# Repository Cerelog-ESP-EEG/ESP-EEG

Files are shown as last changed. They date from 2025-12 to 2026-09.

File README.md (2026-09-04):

# **Cerelog ESP-EEG** 

<table>
  <tr>
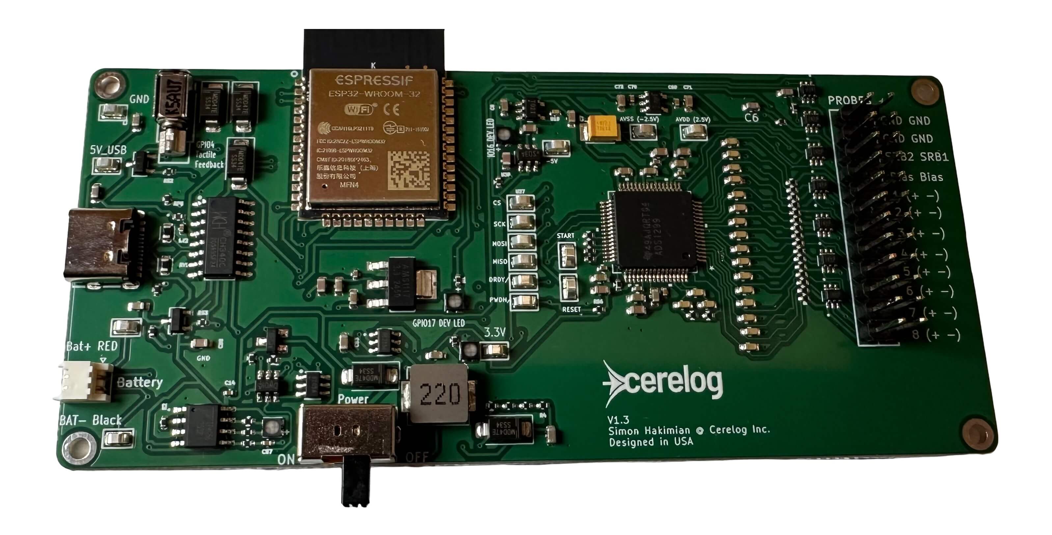
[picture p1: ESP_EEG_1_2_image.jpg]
Cerelog Board V1
    <td align="center"></td>
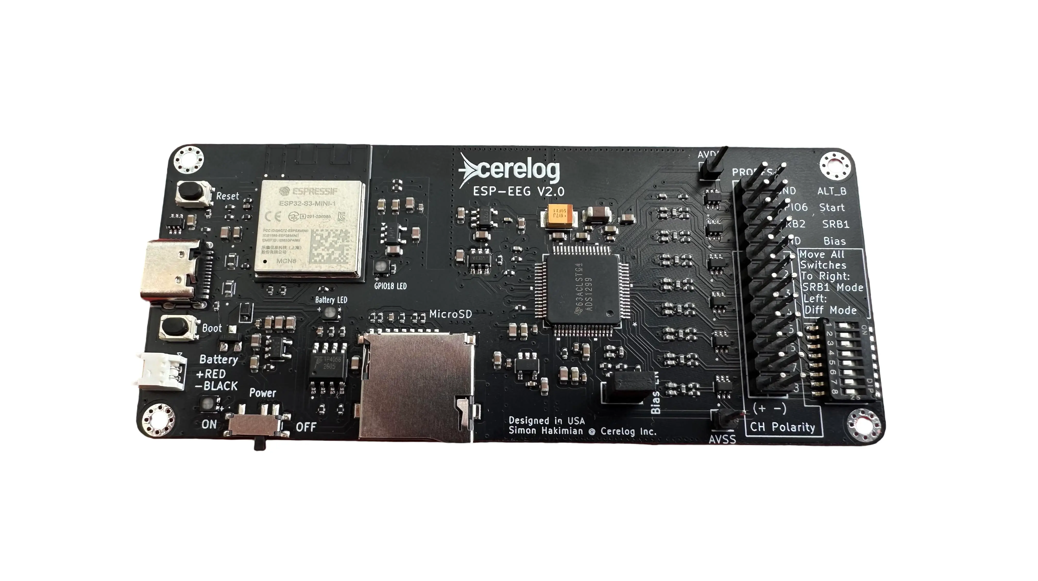
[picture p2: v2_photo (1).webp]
Cerelog Board V2
    <td align="center"></td>
  </tr>
  <tr>
    <td align="center"><b>V1</b></td>
    <td align="center"><b>V2</b></td>
  </tr>
  <tr>
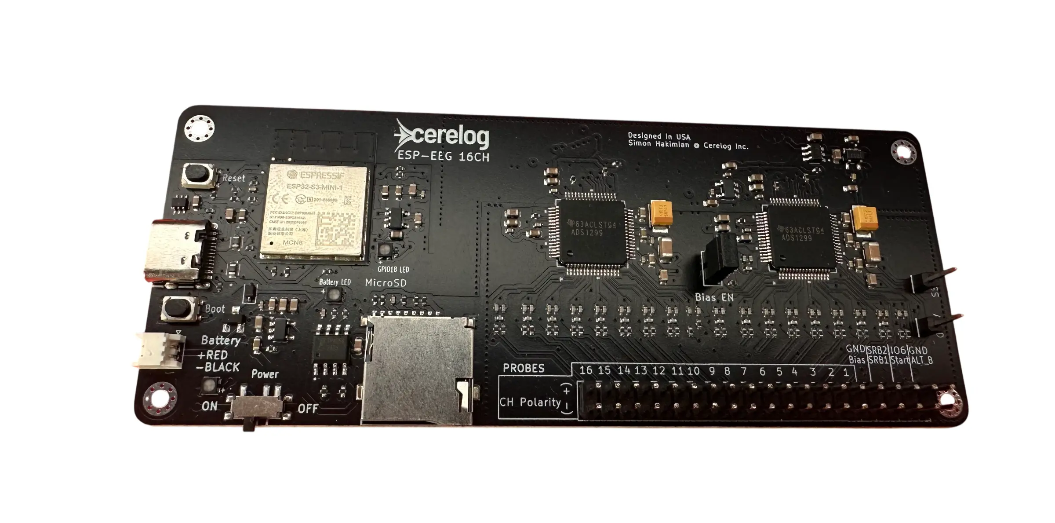
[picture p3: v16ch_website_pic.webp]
16ch ESP-EEG
    <td align="center" colspan="2"></td>
  </tr>
  <tr>
    <td align="center" colspan="2"><b>16CH ESP-EEG</b></td>
  </tr>
</table>

##  High-precision 8-channel biosensing board designed for EEG, EMG, ECG, and Brain Computer Interface (BCI) research applications

www.cerelog.com   and   **Product Page (Assembled Units Available)**: [Here](https://www.cerelog.com/eeg_researchers.html) 

Need Help or have a question? [Discord Chat Community](https://discord.com/invite/fVYf44JTua)

Open Source Firmware, Software & Schematic included on this page

# Helpful Links

Contact: simon@cerelog.com

Need Help or have a question? [Discord Chat Community](https://discord.com/invite/fVYf44JTua)

Product Page: [Here](https://www.cerelog.com/eeg_researchers.html)

Product Usage Guide : [Here](https://www.cerelog.com/eeg_researchers_guide.html) and **See Instructions file above for device usage**

Video Product Overview: [Here](youtube.com/watch?v=6XKdIbguI00&embeds_referring_euri=https%3A%2F%2Fwww.cerelog.com%2F)

3D Print your own case [Here](https://github.com/Cerelog-ESP-EEG/3D-print-Case/tree/main)

Connecting Photo

Helpful [troubleshooting guide](https://github.com/Cerelog-ESP-EEG/Troubleshooting_connection/tree/main )

# Why Cerelog's ESP-EEG? 

## Easy to use Software compatability:

## Compatable with **OpenBCI Gui (Custom fork)** via **Lab Streaming Layer (LSL) ** protocol [(What is LSL?)](https://labstreaminglayer.org/#/) 

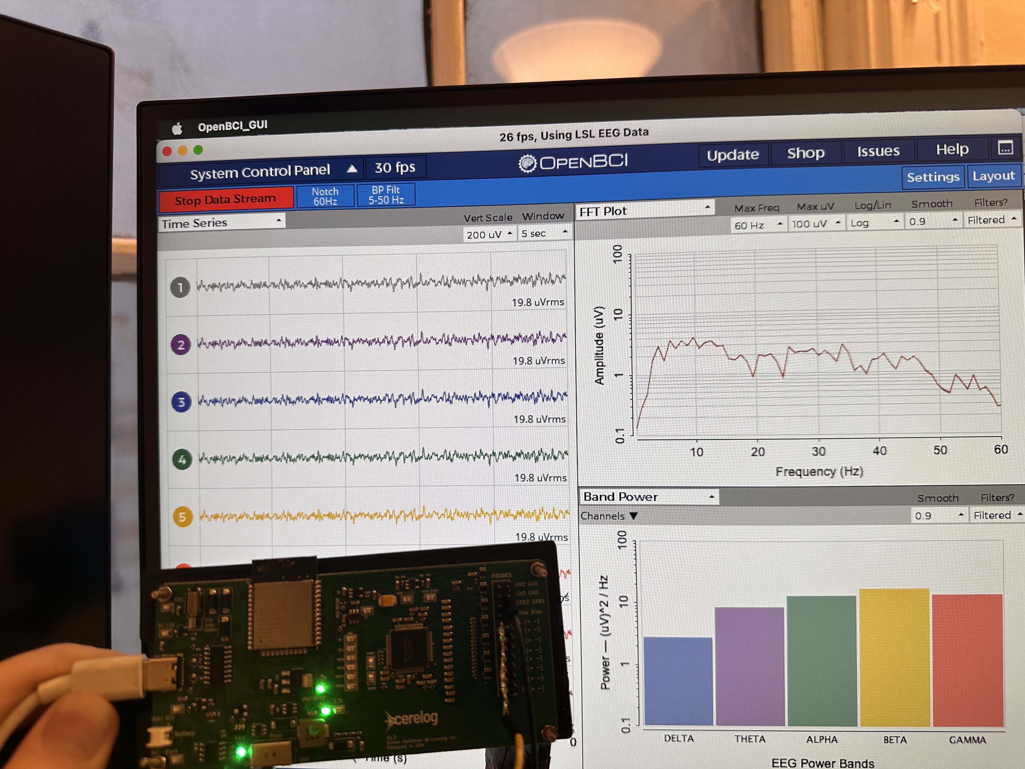
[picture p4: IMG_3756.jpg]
Demo


## USING the custom Forked OpenBCI GUI: 
Setup instructions and LSL Custom Python connection script :  [Here](https://github.com/Cerelog-ESP-EEG/How-to-use-OpenBCI-GUI-fork)

A modified OpenBCI Gui has been forked above so you can visualize data easily and stream to other platforms. This works with it's LSL streaming capability via a special python script (in link above)!

ESP-EEG’s Python client software can stream data via the standard neuroscience software communication protocol Lab Streaming Layer. This means you can stream  directly to your favorite neuroscience software or Matlab running on your laptop or remote computers, record data streams, and integrate ESP-EEG's data with other data streams.

## Stream data to Brainflow API for complex data analysis :


Instructions on how to collect data from device with Brainflow API custom instance: [Here](https://www.cerelog.com/eeg_researchers_guide.html)

and

Custom instance of Brainflow Repo: [Here](https://github.com/shakimiansky/Shared_brainflow-cerelog) for collecting data with the device. 

Note: Test script to quickly view plot and aquire data -> Run 'Shared_brainflow-cerelog/python_package/cerelog_tests/filtered_plot.py' from in above repo. (Must download and run with full Brainflow instance to use)

**2 Quick Videos Using Cerelog ESP-EEG with Brainflow:**

Make sure to read the above linked guide as it is very detailed. If you get stuck with setup, checkout these videos below:

[ESP-EEG with Brainflow](https://www.youtube.com/watch?v=hLSeSTvoRPI)  

[General Product usage Overview Video](youtube.com/watch?v=6XKdIbguI00&embeds_referring_euri=https%3A%2F%2Fwww.cerelog.com%2F)

**Link above links to youtube videos**

## Demo of EMG
# ESP-EEG Robotic Hand Controller 🤖

A demonstration of using the EMG capability of the ESP-EEG bio-signal sensor to control a robotic hand.

ESP-EEG Robotic Hand Demo (https://youtube.com/shorts/xjNg0UMrPlc?si=EgGIO7fhjGFAiRqD)  
*(Click the image above to watch the demo on YouTube)*

[Github code for EMG robotic hand control](https://github.com/Cerelog-ESP-EEG/Robotic_Hand_EMG_-ESP-EEG_Cerelog-)

## Demo of
# Playing Pong with DIY Brain Computer Interface w/ (Cerelog ESP-EEG) using SSVEP Tech 🤖

A demonstration of using the ESP-EEG bio-signal sensor to play Pong using SSVEP technology.

Playing Pong with DIY Brain Computer Interface Demo (https://www.youtube.com/watch?v=3dJWuXLpif8)
*(Click the image above to watch the demo on YouTube)*

[Instructables: Playing Pong With Your Mind – DIY Brain Computer Interface](https://www.instructables.com/Playing-Pong-With-Your-Mind-DIY-Brain-Computer-Int/)

 ## PhantomLoop Integration — Browser Based Neural Decoder *(Beta Testing)*         
                                                                                     
  **A decoder is a small program — usually a machine-learning model — that looks at  
  those signals and guesses what the person was thinking or trying to do.**          
                                                                                     
  A community-built browser-based decoder playground. Stream live EEG data from your 
  ESP-EEG, run an ML model on it, and see predicted vs. actual outputs side by side —
   no local install needed. Built by community member yelabbassi; third-party.       
                                                                                     
  [Learn more about PhantomLoop
  →](https://www.cerelog.com/community_phantomloop.html)

## NEW: WiFi Support - (Beta Testing) - For Use With OpenBCI GUI Fork / LSL
WiFi Logo

[More info](https://github.com/Cerelog-ESP-EEG/WiFi_Support)

## 📉 Superior Noise Reduction (Closed-Loop Bias)
Unlike many consumer EEG devices that use "open-loop" or passive grounding strategies, the ESP EEG implements a **True Closed-Loop Active Bias** (Drive Right Leg).

*   **The Problem:** Many competitors leave the bias feedback loop open, rendering the noise cancellation ineffective against movement artifacts and 50/60Hz hum. Their bias pin effectively becomes the average of the supply rails and acts as a ground on their device making the bias pin not function as effectively intended on the ADS1299 datasheet.
*   **Our Solution:** We utilize the full capability of the ADS1299 to measure the common-mode signal, invert it, and actively drive it back into the body.
*   **The Result:** A significantly lower noise floor and fewer artifacts, allowing for research-grade data capture even in non-shielded environments.

# Hardware Overview

View hardware folder for device schematic

## 🔌 Hardware Pinout & Indicators
*   **Status LED (GPIO 17):**
    *   🟢 **Solid On:** Firmware loaded, ready to stream.
    *   ⚫ **Off:** Board not powered or boot failure.
*   **Battery LED:**
    *   🔴 **Red:** Charging.
    *   🟢 **Green:** Fully Charged.
*   **Battery Connector:** JST-PH 1.25mm (Red = +, Black = -). *Supports 3.7V LiPo.*
*   **Electrodes:** Standard touch-proof headers. (Pins 1-8 = Signal, SRB1 = Reference).
## ⚡ Technical Specifications
| Feature | Specification |
| :--- | :--- |
| **ADC** | Texas Instruments ADS1299 (24-bit, Research Grade) |
| **Channels** | 8 Differential Channels + 1 Active Bias (Noise Cancellation) |
| **Sample Rate** | 250 SPS (Default)  |
| **Processor** | ESP32-WROOM-DA (Dual Core, WiFi/BT capable) |
| **Connectivity** | USB-C (Data/Power) & WiFi/Bluetooth (Hardware Ready) |
| **Montage** | Referential (SRB1 = Ref) by default. Configurable to Sequential. See firmware folder for more information|

# Firmware

View firmware folder for firmware and modification instructions

# ⚠️ CRITICAL SAFETY WARNING
**NON-ISOLATED DEVICE: BATTERY OPERATION REQUIRED**

This device **does not** contain galvanic isolation circuitry. To ensure user safety and prevent ground loops:
1.  **ALWAYS** use this device with a laptop running on **BATTERY POWER**.
2.  **NEVER** connect this device to a computer that is plugged into a wall outlet (Mains Power).
3.  **NEVER** use this device on a desktop computer.

Failure to follow these instructions introduces a risk of electric shock in the event of a mains surge and will significantly degrade signal quality due to ground noise.

# Important Notice
This product is intended for research, engineering, and educational purposes only. It is not a medical device and has not been evaluated by the FDA. The product is not UL or FCC certified.

This evaluation board/kit is intended for use for ENGINEERING DEVELOPMENT, DEMONSTRATION, OR EVALUATION PURPOSES ONLY and is not considered by Cerelog Inc. to be a finished end-product fit for general consumer use.

We expressly disclaim any liability whatsoever for any direct, indirect, consequential, incidental or special damages, including, without limitation, lost revenues, lost profits, losses resulting from business interruption or loss of data, arising from the use of this product.

Only plug this device into a computer running off of battery power such as a Laptop running on its own battery supply or a raspberry pi powered by a portable battery bank. Do not connect to a mains powered device such as a PC because it is not isolated in the event of a power surge. 

Cerelog Inc. assumes no liability for the performance, suitability, or use of any third-party products linked or recommended on this website.

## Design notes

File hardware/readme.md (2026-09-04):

# ESP EEG Hardware Reference

This directory contains the schematics for the ESP EEG platform by Cerelog Inc.

We love the hacker community! We explicitly grant permission for **Personal & Educational Use**.

*   **Can I build my own ESP EEG?**
     If you are a student, hobbyist, or researcher, you are welcome to use our schematics to layout and assemble your own version of this board for your own personal use.

*   **Can I sell the board I built?**
    NO. You may not sell devices based on this design. The license is strictly **Non-Commercial**.

*   **Where are the PCB Layout files?**
    We do not release the PCB layout (Gerber) files. To build your own, you will need to re-route the PCB yourself using the provided schematic. We encourage this as an advanced learning exercise in mixed-signal design!

## ⚠️ Licensing & Cloning Policy
**The hardware design files in this repository are strictly for NON-COMMERCIAL use.**

*   ✅ **Students/Researchers:** You are free to view these schematics to understand your data, debug your board, or modify your own unit.
*   ✅ **Hobbyists:** You are free to repair your own board.
*   ❌ **Commercial Entities:** You may **NOT** use these files to manufacture boards for sale.

**Why?**
Cerelog Inc. is a small, independent company. The sales of this hardware support the development of the open-source firmware, software, and future products. 
We have chosen **not** to release the PCB layout (Gerber) files at this time to prevent low-quality clones from flooding the market and undermining our ability to support this platform.

## 📂 Contents
*   v1,v2, 16CH ESP-EEG Full circuit diagrams for educational and repair purposes.

## ⚡ Safety Disclaimer
**THIS IS NOT A MEDICAL DEVICE.**
This hardware is for research and development purposes only. It is not intended for the diagnosis or treatment of any disease. Always use battery power when connected to a human subject.

## 📜 License
The documentation in this folder is released under the **Creative Commons Attribution-NonCommercial-ShareAlike 4.0 (CC-BY-NC-SA 4.0)** license.

> **Summary:** You can remix, adapt, and build upon this work non-commercially, as long as you credit Cerelog Inc. and license your new creations under the identical terms.

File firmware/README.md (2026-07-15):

## How to flash Firmware with Arduino IDE (Read Carefully!)

Modifying the firmware is necessary to:

- **Change Electrode Montage:** Switch from the default Referential mode to Sequential mode. Sequential mode measures the difference between P and N pins directly, requiring two adapters.
- **Adjust Gain:** Change the Programmable Gain Amplifier (PGA) setting (1, 2, 4, 6, 8, 12, or 24).
- **Control Peripherals:** Write custom code to activate the haptic feedback motor or use the debug LEDs.
- **Change Sample Rate:** This is a highly advanced modification. Altering the sample rate or resolution will change the data stream format and will require you to rewrite the data parsing logic in your software.

I reccomend reading the TIADS1299 datasheet to understand what register changes are needed for what firmware mods. If you have an issue email support@cerelog.com

### Configuring the Arduino IDE

Before flashing `esp32_firmware.ino`, you must configure the IDE with the correct settings:

### Special Arduino IDE Flashing Instructions

> [!CAUTION]
> Caution!!!! You must read the below or the flash wont work

**Board:** Navigate to **Tools > Board > ESP32 Arduino** and select `ESP32 WROOM DA Module`.

> [!IMPORTANT]
> It must be **ESP32 WROOM DA Module** — not the generic "ESP32 Dev Module". Picking the wrong one will flash but the board won't enumerate correctly.

**Port:** Navigate to **Tools > Port** and select the COM port corresponding to your Cerelog board.

> [!WARNING]
> Any other ESP32 name and it will likely not flash! Also, check that the serial rate setting in the Arduino IDE isnt set to the max setting, sometimes its too fast of an upload speed

> [!CAUTION]
> Caution!!!! If not flashing, check that the baud rate setting isn't too high. An upload speed of 115200 is ok but 921600 is too high and too fast of an upload speed. Navigate to **Tools > Upload speed** to check

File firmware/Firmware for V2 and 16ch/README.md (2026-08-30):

# $\textcolor{green}{\textbf{\textsf{Additional Flashing Instructions for V2 and 16 Channel PCBs}}}$

To flash firmware on the **V2** and **16 channel** boards you *must* use the **Arduino IDE**.
The sketch to flash is [`V2_FW/V2_FW.ino`](V2_FW/V2_FW.ino).

---

## $\textcolor{red}{\textbf{\textsf{!! CRITICAL SETTINGS - READ CAREFULLY !!}}}$

**These settings are NOT default and are REQUIRED.**
$\textcolor{red}{\textsf{Without them, the flash may succeed but}}$ $\textcolor{red}{\textsf{the firmware WILL NOT WORK and you}}$ $\textcolor{red}{\textsf{WILL NOT be able to log data.}}$

Set all three in the Arduino IDE **before** you hit Upload:

| # | Setting | Where | Value |
|:-:|---|---|---|
| **1** | Board | `Tools -> Board` | `ESP32-S3 Dev Module` |
| **2** | CDC on Boot | `Tools -> CDC on Boot` | `Enabled` |
| **3** | USB Mode | `Tools -> USB Mode` | `Hardware CDC and JTAG` |

> [!CAUTION]
> **DO NOT SKIP STEPS 2 AND 3.** The flash will appear to succeed, but the firmware will not function and data logging will not work.

---

## If the Flash Fails

| Symptom | Fix |
|---|---|
| Upload errors out / does not complete | `Tools -> Flash Size` &rarr; set to `4MB (32Mb)` |

---

$\textcolor{gray}{\rule{1000px}{8px}}$

# Special Extra Features in Hardware that Users May Desire to Modify Firmware to Accommodate

## Enhanced Hardware Access

The signals below are **broken out on the board but are not used by the stock firmware**. They are here for
users who want to extend the firmware for their own applications.

### $\textcolor{dodgerblue}{\textbf{\textsf{Battery monitoring}}}$ exposed on-board via ESP32 GPIO for custom firmware

Battery life can be monitored by the user: **IO0 (ADC1_CH0)** senses the battery through a resistor divider
network — multiply the measured voltage by **2** to get the real battery voltage.

### $\textcolor{dodgerblue}{\textbf{\textsf{Event sync trigger}}}$ exposed on-board via ESP32 GPIO for custom firmware

Event sync trigger input: **IO6 (ADC1_CH5)** is broken out from the ESP32 for an external trigger —
**3.3&nbsp;V max**, with a current-limiting input resistor. Modify the existing firmware to accept the trigger
for tests that need a sync.

### Quick reference

| Signal | GPIO | ADC channel | Notes |
|---|---|---|---|
| Battery sense | `IO0` | `ADC1_CH0` | Resistor divider — multiply reading by **2** |
| Event sync trigger | `IO6` | `ADC1_CH5` | **3.3 V max**, current-limiting input resistor |

> [!NOTE]
> Hardware capability only — not coded into the default firmware. Intended for users modifying the firmware
> for custom applications.

> [!WARNING]
> Just like the OpenBCI Cyton, the trigger input is **not opto-isolated** — the user is responsible for the
> safety of whatever they plug into it.

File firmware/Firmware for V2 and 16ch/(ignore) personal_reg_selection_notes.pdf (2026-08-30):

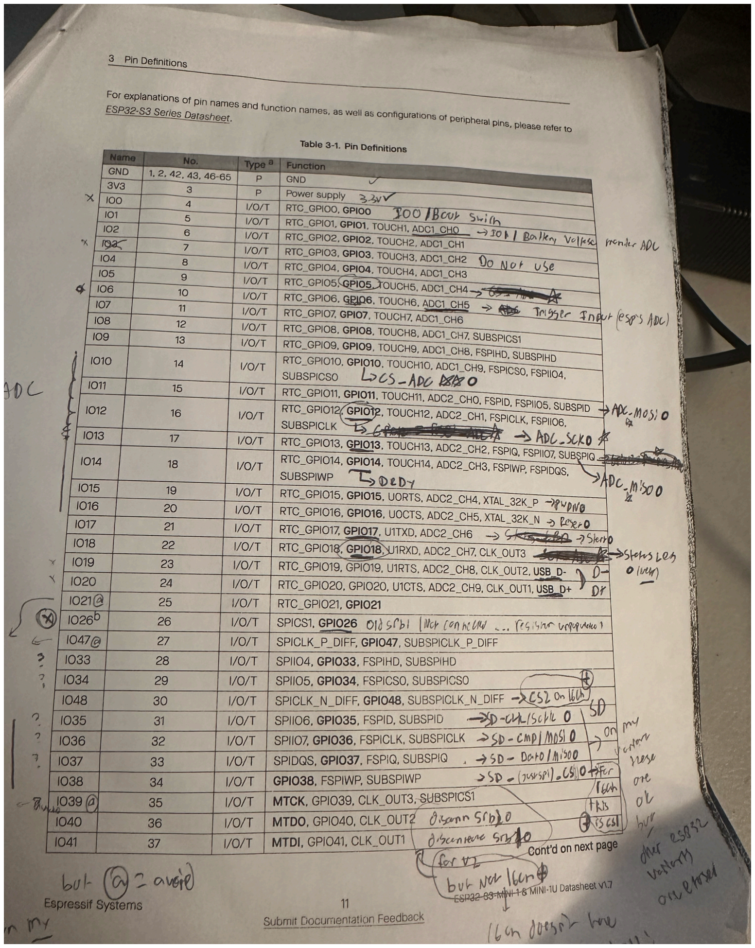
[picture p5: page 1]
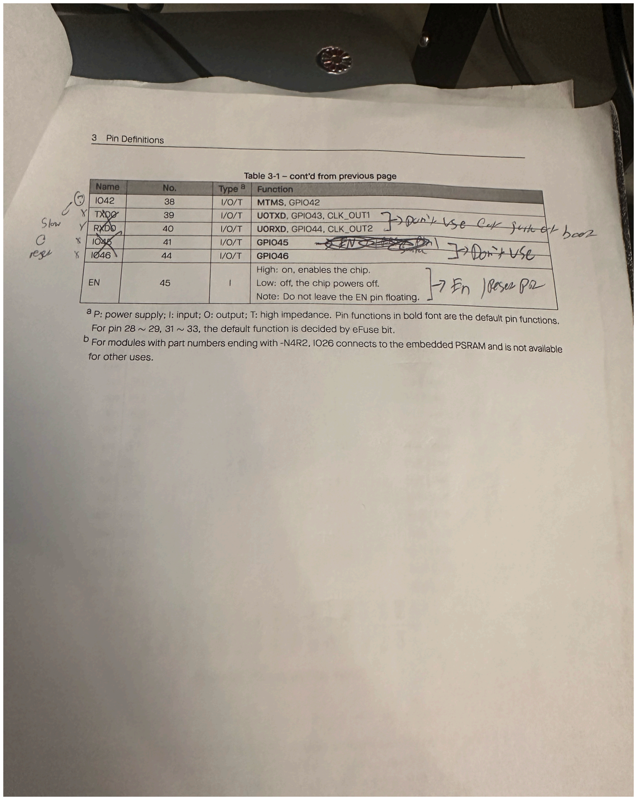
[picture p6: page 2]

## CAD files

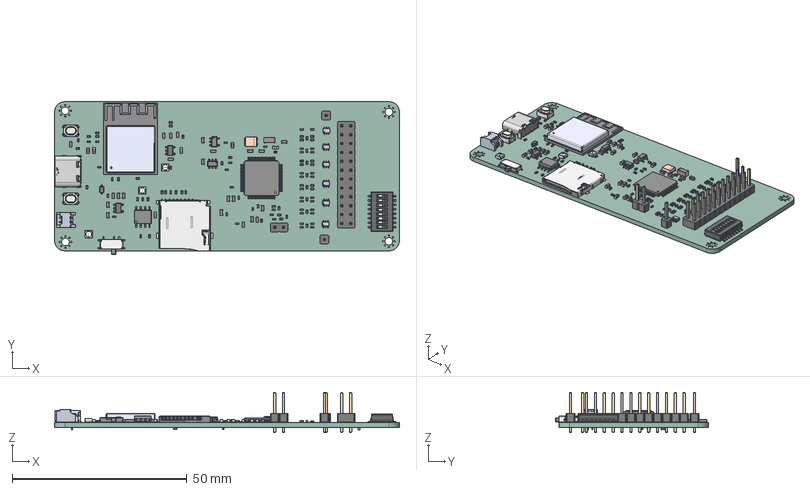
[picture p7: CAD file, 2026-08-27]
3D print Your Own ESP-EEG Case/v2_step.step
98.8 x 43.7 x 11.5 mm
C_0603_1608Metric x 29
C_1206_3216Metric
R_0402_1005Metric x 53
C_0402_1005Metric x 43
SKRPABE010 x 2
v2_step 1.19 x 6
TAJB107K006RNJ
DHA-08TQR
TPS72325DBVR
PinHeader_1x01_P2.54mm_Vertical x 2
PinHeader_2x12_P2.54mm_Vertical
SOT-23-5 x 2
D_SOD-323
C2874116 x 3
ADS1299-6PAG
ESP32-S3-MINI-1-N8
PinHeader_1x02_P2.54mm_Vertical
TF-SMD_TF-01A
TYPE-C-16PIN-2MD-073
TP4056-42-ESOP8
LM2664M6
2_0_PCB

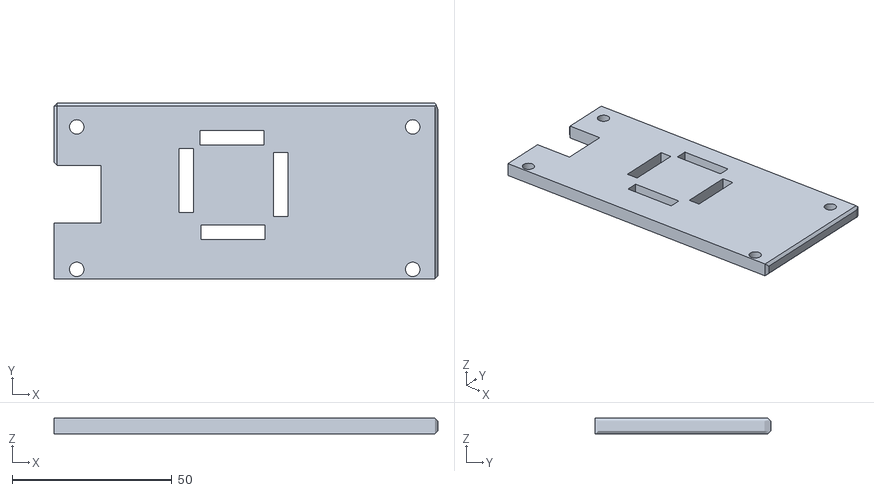
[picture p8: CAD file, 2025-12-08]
3D_Print_your_headset/adaptor.stl
120.0 x 55.0 x 5.00

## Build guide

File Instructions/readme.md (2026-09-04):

# ESP EEG: Quick Start & Software Guide

**⚠️ Note: Full instructions for the device are included in the PDF manual 'product_use_guide_1_6.pdf' which can also be found [here](https://www.cerelog.com/eeg_researchers_guide.html) and I reccomend you read them as they are very detailed. This guide provides the essential steps to quickly get the device running, connected, and plotting data.**

# Need Help or have a question? 

[Discord Chat Community](https://discord.com/invite/fVYf44JTua) 
or email simon@cerelog.com 

**[Troubleshooting guide:](https://github.com/Cerelog-ESP-EEG/Troubleshooting_connection/tree/main )**

---

# 🔌 Part 1: Connecting Hardware & Running a Session

Connecting Photo

## 📋 Which board do you have? (Read this first)

There are three ESP-EEG boards, and a few instructions differ between them. Check this table before following the rest of the guide.

| | **ESP-EEG V1 (8CH)** | **ESP-EEG V2 (8CH)** | **ESP-EEG 16-Channel** |
|---|---|---|---|
| Channels | 8 | 8 | 16 |
| Montage selection | Firmware edit + reflash | **Physical slider switch on the PCB** | **Two slider switch banks on the back of the board** |
| microSD recording | ❌ No card slot | ✅ Onboard microSD slot | ✅ Onboard microSD slot |
| Onboard haptic motor | ✅ Yes | ❌ Removed | ❌ Removed |
| USB driver install | Sometimes (CH340C / CH341SER) | ❌ Not required | ❌ Not required |

The **Part 2** software setup (building BrainFlow, filtering, plotting) is the same procedure on every board. Note that the example scripts in this guide are written for 8 channels and use `BoardIds.CERELOG_X8_BOARD` — 16-Channel users may need to adjust the channel count and plot layout in the scripts.

## 1. Hardware Assembly
Connect your EEG cap cable(s) to the required touch-proof adapter(s), then plug the adapter(s) into the electrode headers on the Cerelog board.

## 2. Prepare the Subject
Fit the EEG cap on the subject's head. Apply a small amount of conductive gel into each electrode cavity to ensure good skin contact.

## ⚠️ CRITICAL SAFETY REMINDER — READ BEFORE CONNECTING ANYTHING

**This board has no medical-grade isolation.** As per the safety notice in Section 1 of the full product guide, only connect the device to a laptop running on its own **battery power**.

*   **DO NOT** use this device if the laptop is charging.
*   **DO NOT** connect this device to a desktop computer plugged into a wall outlet.

---

## 3a. How to connect the circuit board (what pins do what):

Full illustrated version on the website: [Hardware Overview](https://www.cerelog.com/eeg_researchers_guide.html#hardware-overview)

**Pick the section for your board — V1 and V2/16CH are wired differently.**

<details>
<summary><b>🟦 ESP-EEG V1 (8-Channel) — click to expand</b></summary>

<br>

### EEG Setup (Scalp Recording)

*   **SRB1 pin** — This is the negative (–) reference electrode for all 8 channels. Attach an earclip electrode to one ear. Apply conductive gel under the earclip for a good connection.
*   **BIAS pin** — Attach a second earclip electrode to the other ear, also with conductive gel.
*   **CH1+ through CH8+** — Connect these to your headset electrodes of choice. These are the only channel pins you need for a standard EEG setup.
*   **CH1– through CH8–** — Leave these unconnected. In the default firmware configuration these pins are not tied to SRB1 and are not used. Only connect them if you change the montage by editing and reflashing the firmware.

> **Tip:** If you run into signal quality issues, give the **GND** pin a try in place of the BIAS pin on the second earclip — it may help.

> **Is your session starting out flat?** Try starting the session with the **GND** pin connected to your earclip and then swap over to the **BIAS** pin once the session is running. This can help with feedback loop stabilization.

### EMG Setup (Muscle Recording)

To record one channel of EMG data (e.g. forearm muscles):

*   **CH1+** — Place on the top of the forearm (over the muscle belly).
*   **SRB1** — Place on the bottom of the forearm as the negative (–) reference.
*   **GND pin** — Place on the elbow. For EMG, the GND pin works best as the ground reference rather than the BIAS pin.

### ⚠️ Not Using All 8 Channels?

For best results, all 8 channels should be in use. If you are using fewer than 8 channels, you should either **tie the unused CH+ pins to one of the active CH+ pins** (connect them together physically), or **disable the unused channels in the firmware** and reflash the board.

If unused channels are left floating (unconnected and enabled), the BIAS pin will be less effective at eliminating noise, resulting in **poorer signal quality across all channels**.

</details>

<details>
<summary><b>🟩 ESP-EEG V2 (8-Channel) & 16-Channel — click to expand</b></summary>

<br>

These boards support **both** a referential montage (SRB1) and a differential montage (CH+ / CH–), and you choose between them with the **physical slider switch(es) on the PCB — not in software.**

### Choose Your Path: Set the Switch, Then Wire It

The montage is selected by the slider switch on the PCB, and the switch position determines how you wire your electrodes. Pick one of the two paths below and follow it end to end — **they are mutually exclusive.**

> **⚠️ Tip:** The montage switches are deliberately stiff and hard to move with your fingers. Use a **sewing pin or the tip of a pencil** and slide them slowly and carefully into position — **do not force them.** 16-Channel boards have **two montage switch banks on the back of the board** instead of one; **both must be set to the same mode**, whichever path you take.

---

#### Path A — Referential Montage (SRB1)

**Best for:** scalp EEG and most EMG. This is the standard mode.

**1. Set the switch:** move **all switches to the right**. This puts the board in SRB1 referential montage mode. On 16-Channel boards, set **both** switch banks to the right.

**2. Wire your electrodes:** in this mode SRB1 is the shared negative (–) reference for every channel, and BIAS drives noise cancellation. A two-channel example:

*   **CH1+ and CH2+** — connect to your two recording sites (scalp electrodes for EEG, or over the muscle belly for EMG).
*   **SRB1** — connect to one earclip electrode, with conductive gel. This is the negative (–) reference shared by both channels.
*   **BIAS** — connect to the earclip on the other ear, also with conductive gel.
*   **CH1– through CH8–** (CH16– on 16-Channel boards) — leave these **unconnected** in referential mode.

The same pattern scales to any number of channels: every CH+ you use goes to a recording site, SRB1 to one earclip, BIAS to the other.

---

#### Path B — Differential Montage (CH+ / CH–)

**Best for:** measuring between two specific points, such as a single muscle in EMG.

**1. Set the switch:** move the switches to the **opposite position (not to the right)**. Each channel then measures between its own CH+ and CH– pins instead of against the shared SRB1 reference. On 16-Channel boards, set **both** switch banks the same way.

**2. Wire your electrodes:**

*   **CH1+ and CH1–** — connect this pair across the two points you want to measure between. Repeat per channel: CH2+ / CH2–, CH3+ / CH3–, and so on.
*   **SRB1** — not used as the reference in this mode.
*   **BIAS** — still connect it (see the BIAS pin note below); noise cancellation works the same way in both modes.

---

### 🚨 CH1 Must Always Be Connected (both paths)

**CH1 is the minimum electrode that must be attached to the user.** You cannot, for example, record three channels using only channels 2, 3 and 4 — one of the channels you use must physically be **CH1**. The BIAS pin stabilises the signal and removes noise through a feedback loop that **runs through Channel 1**, so without CH1 connected the BIAS circuit has nothing to work against.

For the same reason, **a poor CH1 connection degrades BIAS performance across every channel.** Give CH1 the best, lowest-impedance contact of all your electrodes — plenty of conductive gel and a firm, stable placement.

### One Register to Leave As-Is: SRB1 Enable

Montage selection on V2 and 16-Channel boards is handled by the **slider switch on the PCB**, so the SRB1 enable bits are set in firmware to work with that switch and **should be left at their default value**. If you want to switch between referential and differential mode, **move the switch** rather than changing this register — toggling SRB1 enable in firmware will not select a montage on these boards. The rest of the firmware is yours to modify as usual.

### A Note on the BIAS Pin: BIAS_EN Header & Alternative Bias Options

*   **BIAS_EN header** — must be in place (jumper installed) for the BIAS pin to work. This is the normal configuration for EEG and for most EMG.
*   **ALT_B pin** — for some niche EMG applications, ALT_B may work as an alternative bias pin. It can **only** be used with the BIAS_EN header **removed**.
*   **GND pin** — a third option worth trying for EMG. Expect worse performance than BIAS or ALT_B; its purpose is to keep the subject near the centre of the supply so readings stay within the board's rail limits.

### Optional: AVDD & AVSS Header Pins (Powering Active Electrodes)

The board exposes **AVDD** and **AVSS** header pins, which connect to the ADC supply's **+2.5 V and –2.5 V** inputs. If you are using ThinkPulse active electrodes, you can power them from the board's own supplies through these pins. *Cerelog is not affiliated with ThinkPulse.*

### 16-Channel Boards

Every rule above applies identically — there are simply **16 channels instead of 8**, and **two montage switch banks on the back of the board** rather than one.

</details>

## 3b: (For V2 and 16CH devices) Info on using microsd card for data collection

Full version on the website: [Hardware Overview](https://www.cerelog.com/eeg_researchers_guide.html#hardware-overview)

<details>
<summary><b>💾 Recording to microSD (ESP-EEG V2 & 16-Channel only) — click to expand</b></summary>

<br>

The ESP-EEG **V2** and **16-Channel** boards include an onboard microSD card slot, which the original V1 board does **not** have. It lets you record a session directly to a card on the board instead of streaming to a computer.

### ⚠️ Insert the Card Before You Power On

The microSD card **must already be inserted before you turn the device on** with the power switch. The card is detected at **start-up only** — inserting it after the board is powered will not start a recording.

### Choosing a Card

*   **Capacity:** most cards of **32 GB or less** will work, provided they are **FAT32** formatted. Cards larger than 32 GB, or cards using a different file system, may not work.
*   **Wrong format or too large?** You can reformat the card with your computer's disk utility — aim for a **FAT32 volume of 32 GB or under**.
*   **High-endurance cards are recommended for long recording runs.** They significantly reduce the risk of file corruption or interruption over many hours of continuous writing.

### What Gets Recorded

Each run produces **one CSV file** on the card. Every row is one sample, with the following columns:

*   **Timestamp** — milliseconds since the log started (**not** wall-clock time).
*   **Status** — the 3-byte status word emitted by the ADS1299 with every sample, written in hex. It carries the ADC's sync pattern along with lead-off and GPIO flags.
*   **CH1 … CH8** — one column per channel, holding **signed ADC counts** (raw 24-bit conversion results, **not volts**). On 16-Channel boards this runs **CH1 … CH16** instead.

So a row reads:

```
timestamp_ms, status_hex, ch1, ch2, … ch8      (or … ch16)
```

### Converting ADC Counts to Voltage

The channel columns are raw signed ADC counts. To convert them (V = 4.5 V, gain = 24 by default):

```python
scale_factor = (2 * 4.5 / 24) / (2**24)   # = 2.2352e-8 V per count
microvolts = raw_val * scale_factor * 1000000
```

### 🚨 Verify Your Recording Before a Long Run

**You are responsible for confirming that data collection is actually in progress.**

Before committing to a long or overnight session, do a short test run first: power the board with the card inserted, record for a minute, then check that the CSV exists on the card and contains sensible data. It is far better to catch a bad card, a bad format, or a loose electrode in a one-minute test than after eight hours of recording.

</details>

## 3c. Advice on Collecting Clean Data

*   **High-Voltage Spike Fix:** If you see large voltage spikes in your data caused by environmental interference, try starting your session with the **GND** pin on the second earclip instead of the BIAS pin. Once the signal stabilizes, swap the earclip back to the **BIAS** pin — the data should return to normal. This helps the board's internal feedback loop settle and reduces environmental ringing before the BIAS-driven noise cancellation takes over.
*   **Non-Standard Mains Frequency:** The test scripts in the Cerelog test suite (including `filtered_plot.py` and others) have hardcoded notch-filter frequencies for **50 Hz and 60 Hz**, which covers most countries. However, if you live in a region where the power grid suffers from strong frequency instability or operates at a non-standard mains frequency, you will need to manually edit the frequency variable in whichever test script you are using to match your local mains frequency and effectively remove that noise from your recordings.
*   **Use the BIAS probe correctly.** It is the single most important tool for noise cancellation — it measures the mains hum from the body and subtracts it from the EEG channels. Ensure the ear clips used for BIAS and SRB1 have plenty of conductive gel.
*   **Jaw clench looks small? That's normal.** Because of the board's effective BIAS filtering, you may not see massive screen-filling spikes when clenching your jaw, unlike on cheaper or older hardware. It means the board is successfully filtering out the muscle noise.

## 4. Connect the board

## **[Note: If your device (after doing Part 2 instructions below) can't connect the computer to the device, read this helpful [troubleshooting guide:](https://github.com/Cerelog-ESP-EEG/Troubleshooting_connection/tree/main )]**

Connect the board to your computer via USB-C. Wait for green LED to turn on. 

⚠️ Don't see the LED turn on? 
Sometimes you may need to turn on and off PCB for computer to detect new board. If you do not see this status LED turn on after 10 seconds you need to powercycle with switch. Also, if the LIPO battery is dead you will need to charge it with USB-C. After plugging in a new battery you must also turn on and off the power switch.

**Don't Like USB?:  WiFI Support (Under Dev)**
[More info](https://github.com/Cerelog-ESP-EEG/WiFi_Support)

---

# 💻 Part 2: Software Setup & Advanced Analysis

> **⚠️ Driver installation applies to V1 devices only.** **ESP-EEG V2 and 16-Channel boards do not require driver installation** — modern operating systems detect them automatically. Skip the two driver links below unless you own a V1 (or your Raspberry Pi still fails to see the board).

**If you own a Raspberry Pi: Driver setup first  -> [Read Here:](https://github.com/Cerelog-ESP-EEG/ESP-EEG/blob/main/Instructions/subguides/raspberrypi/readme.md)** 

and

**Other Linux Users: Driver setup first  -> [CH341SER Driver Here:](https://www.wch-ic.com/downloads/CH341SER_EXE.html)** 

# *⚠️Option A (NEW and Easy) Use with the modified version of the OpenBCI GUI  or Lab Stream Layer (LSL) here: 

https://github.com/Cerelog-ESP-EEG/How-to-use-OpenBCI-GUI-fork 

# Option B (Best) To learn how to use with Brainflow keep reading: 

To get the best performance from the ESP EEG, we recommend using our custom BrainFlow instance. This guide covers installation, the theory behind our data stream, and provides a production-grade script for real-time filtering and plotting.

**2 Quick Videos Using Cerelog ESP-EEG with Brainflow:** Use these videos if you get stuck with the GUIDE BELOW. Make sure to read the instructions below though, as the videos don't have all of the setup command scripts.

[ESP-EEG with Brainflow](https://www.youtube.com/watch?v=hLSeSTvoRPI)  and [General Product usage Overview Video](youtube.com/watch?v=6XKdIbguI00&embeds_referring_euri=https%3A%2F%2Fwww.cerelog.com%2F)

# How to use Brainflow [READ THIS!]:

## Step 1: Installation (Custom BrainFlow Instance)

The ESP EEG requires a specific version of BrainFlow to handle its high-fidelity data packets correctly.

1.  **Download the Custom Library:**
    Clone or download the custom BrainFlow repository here:
    👉 **[Cerelog Shared BrainFlow Repository](https://github.com/shakimiansky/Shared_brainflow-cerelog)**

**Seting up the brainflow repo on new computers:**

*   **One-Time Setup:** This compilation is a one-time setup for your computer.
*   **Why compile?** Because the core library is written in C++, it must be compiled specifically for your operating system (Windows, Mac, or Linux).
*   **When to repeat:** You only need to repeat the build process (Step 2) if you modify the underlying C++ source code files (`.cpp`, `.h`). Creating new Python scripts does **not** require a rebuild but it does require running pip install -e. (the last step) before running new python scripts

---

## Step 2: Get the Custom BrainFlow Fork
Our board requires a specific fork of BrainFlow. Clone it and navigate into the new directory.

> **⚠️ IMPORTANT: Use This Specific Repository**
> This version of BrainFlow contains code specific to the Cerelog board. This code has not yet been merged into the official, main BrainFlow repository. You **must** use the link provided below.

```bash
git clone https://github.com/shakimiansky/Shared_brainflow-cerelog.git
cd Shared_brainflow-cerelog
```

---

## Step 3: Build the Library from Source
This crucial step compiles the C++ core of the library.
*Tip: If you make a mistake, manually delete the `build` folder and start this step over.*

### 🍎 macOS and Raspberry Pi/Linux Users: Install Build Tools First
Before proceeding, you need to install Homebrew (a package manager) and CMake. Open a terminal and run these commands one by one:
```bash
/bin/bash -c "$(curl -fsSL https://raw.githubusercontent.com/Homebrew/install/HEAD/install.sh)"
```

macOS only: 
```bash
brew install cmake
```

Raspberry Pi (Linux): Raspberry Pi OS uses apt instead of Homebrew. Install CMake by running:
```bash
sudo apt install cmake
```

### 🛠️ Compilation Steps (All OS)

**1. Create the build directory:**
Create a new directory named `build` inside the `Shared_brainflow-cerelog` folder and navigate into it.
```bash
mkdir build
cd build
```

**2. Prepare build files (Choose your OS):**
Run the correct `cmake` command for your operating system.

*   **For Windows (with Visual Studio 2022):**
    ```bash
    cmake .. -G "Visual Studio 17 2022" -A x64
    ```

*   **For macOS / Linux:**
    ```bash
    cmake ..
    ```

** Run the Build Command:**
This uses 4 processor cores (`-j4`) for faster compilation.
```bash
cmake --build . --config Release --clean-first -j4 -- -k
```

---

## Step 4: Install the Python Package
With the core library built, you must install the Python bindings to link your scripts to the C++ core.

**Raspberry Pi Users: Create a Virtual Environment First**

Raspberry Pi OS requires you to use a Python virtual environment before installing packages. Run these commands before proceeding with the steps below:

```bash
python3 -m venv ~/cerelog-venv
source ~/cerelog-venv/bin/activate
```

> **Note:** You will need to re-activate the virtual environment with `source ~/cerelog-venv/bin/activate` each time you open a new terminal session.

## All Users:

**1. Navigate to the python package folder:**
(Move up from the `build` folder and into `python_package`)
```bash
cd ..
cd python_package
```

**2. Install in "Editable" Mode:**
This links the package to the source files, so you don't need to reinstall the pip package if you change python files later. This command only needs to be run once.

*   **Windows / Linux:**
    ```bash
    pip install -e .
    ```
*   **macOS:**
    ```bash
    pip3 install -e .
    ```
## Step 5: Dependencies
Ensure you have the required Python packages installed:
```bash
pip install numpy matplotlib pyserial plotly dash scikit-learn "setuptools<82"
# Note: brainflow must be installed/referenced from the custom repo above
```

## Step 6   Run Test Script

<table>
<tr>
<td>

<details>
<summary>$\Large\textcolor{red}{\textsf{Raspberry Pi Users: Read This First}}$</summary>

### 1. Activate Your Virtual Environment

Before running any test scripts, make sure your virtual environment is active. If you opened a new terminal since Step A.3, re-activate it:

```bash
source ~/cerelog-venv/bin/activate
```

### 2. Hardcode the Serial Port

All BrainFlow test scripts — including `filtered_plot.py` — must have the serial port name hardcoded to run on Raspberry Pi. Automatic port detection does not work on Pi.

In each script, find the line:

```python
params = BrainFlowInputParams()
```

And add the following line directly after it:

```python
params.serial_port = "/dev/ttyCH341USB0"
```

You must make this edit in **every** BrainFlow test script you want to run on the Pi.

### 3. Running Test Scripts Over SSH

Test scripts that display plots must be run from the Raspberry Pi's own terminal. If you are connected over SSH, the plot window cannot open on your remote machine by default. To run a script over SSH and have the plot display on the Pi's screen, prefix the command with `DISPLAY=:0`:

```bash
DISPLAY=:0 python filtered_plot.py
```

</details>

</td>
</tr>
</table>

## Running the first Brainflow Testscript 

The script below (`filtered_plot.py`)  relies on the bindings found in the Brainflow repository. You must run the script **inside** that repository's environment or install the Python bindings from that source.

Run it by saying python filtered_plot.py or on mac OS python3 filtered_plot.py inside the correct folder

## **[Note: If you can't connect the computer to the device, read this helpful [troubleshooting guide:](https://github.com/Cerelog-ESP-EEG/Troubleshooting_connection/tree/main )]**

##  Run the Script
Below is the complete Python script for robust, real-time plotting. Save this code as `filtered_plot.py` inside your custom BrainFlow folder.

<details>
<summary>🛠️ $\textcolor{red}{\textsf{Troubleshooting: }\texttt{ModuleNotFoundError: No module named 'pkg\_resources'}}$</summary>

<br>

This happens because newer versions of **setuptools** have removed the legacy
`pkg_resources` module. To fix it, downgrade setuptools:

**macOS / Linux**
```bash
python3 -m pip install "setuptools<82"
```

**Windows**
```bash
python -m pip install "setuptools<82"
```

</details>

**Scroll down past the code to learn how it works.**

```python
import time
import numpy as np
import matplotlib.pyplot as plt
from matplotlib.animation import FuncAnimation
from brainflow.board_shim import BoardShim, BrainFlowInputParams, BoardIds, BrainFlowError
from brainflow.data_filter import DataFilter, FilterTypes
from brainflow.data_filter import NoiseTypes, DetrendOperations, AggOperations, WaveletTypes, NoiseEstimationLevelTypes, WaveletExtensionTypes, ThresholdTypes, WaveletDenoisingTypes

# --- Configuration ---
BOARD_ID = BoardIds.CERELOG_X8_BOARD
SECONDS_TO_DISPLAY = 10
UPDATE_INTERVAL_MS = 40
Y_AXIS_PADDING_FACTOR = 1.2

# --- Global variables ---
board = None
eeg_channels = []
sampling_rate = 0
window_size = 0
data_buffer = np.array([])
y_limits = {}

def main():
    """
    Connects to the Cerelog board and creates a robust, real-time, scrolling plot
    with stable filtering and adaptive scaling.
    """
    global board, eeg_channels, sampling_rate, window_size, data_buffer, y_limits

    params = BrainFlowInputParams()
    params.timeout = 15
    board = BoardShim(BOARD_ID, params)

    try:
        eeg_channels = BoardShim.get_eeg_channels(BOARD_ID)
        sampling_rate = BoardShim.get_sampling_rate(BOARD_ID)
        window_size = SECONDS_TO_DISPLAY * sampling_rate

        if sampling_rate <= 0:
            raise BrainFlowError("Could not get a valid sampling rate from the board.", 0)

        for i in range(len(eeg_channels)):
            y_limits[i] = (-100, 100)

        print(f"Connecting to {board.get_board_descr(BOARD_ID)['name']}...")
        print(f"Detected Sampling Rate: {sampling_rate} Hz")
        board.prepare_session()
        print("\nStarting stream... Close the plot window to stop.")
        board.start_stream(5 * 60 * sampling_rate)
        time.sleep(2)

        num_board_channels = BoardShim.get_num_rows(BOARD_ID)
        data_buffer = np.empty((num_board_channels, 0))

        # --- Plot Setup ---
        fig, axes = plt.subplots(4, 2, figsize=(18, 10), sharex=True)
        fig.suptitle('Real-Time Cerelog EEG Waveforms (Correct Time Spacing)', fontsize=16)
        axes_flat = axes.flatten()
        lines = [ax.plot([], [], lw=1)[0] for ax in axes_flat]

        for i, ax in enumerate(axes_flat):
            ax.set_title(f'Channel {eeg_channels[i]}')
            ax.set_ylabel('Voltage (µV)')
            ax.grid(True)
            ax.set_xlim(-SECONDS_TO_DISPLAY, 0)

        fig.text(0.5, 0.04, 'Time (Seconds from "Now")', ha='center', va='center')
        plt.tight_layout(rect=[0, 0.05, 1, 0.96])

        def on_close(event):
            print("Plot window closed, stopping stream...")
            if board and board.is_prepared():
                board.stop_stream()
                board.release_session()
            print("Session released. Exiting.")

        fig.canvas.mpl_connect('close_event', on_close)

        ani = FuncAnimation(fig, update_plot, fargs=(lines, axes_flat), interval=UPDATE_INTERVAL_MS, blit=False)
        plt.show()

    except Exception as e:
        print(f"An error occurred in main(): {e}")
    finally:
        if board and board.is_prepared():
            board.release_session()

def update_plot(frame, lines, axes):
    """
    This function is called periodically to update the plot data.
    """
    global data_buffer, y_limits

    try:
        new_data = board.get_board_data()
        if new_data.shape[1] > 0:
            data_buffer = np.hstack((data_buffer, new_data))
            buffer_limit = int(window_size * 1.5)
            if data_buffer.shape[1] > buffer_limit:
                data_buffer = data_buffer[:, -buffer_limit:]

        plot_data = data_buffer[:, -window_size:]
        
        num_points = plot_data.shape[1]
        if num_points < 2:
            return

        eeg_plot_data = plot_data[eeg_channels] * 1e6
        
        # --- Filtering Logic (Corrected for Real-Time Stability) ---
        for i in range(len(eeg_channels)):
            # Use a safe data length check for the filters
            if eeg_plot_data[i].size > 20: 
                #1 Detrend to get dc offset away
                DataFilter.detrend(eeg_plot_data[i], DetrendOperations.CONSTANT.value)
                # 2. Apply a STABLE 4nd-order low-pass 100hz. This is crucial for real-time processing.
                DataFilter.perform_lowpass(eeg_plot_data[i], sampling_rate, 100.0, 4, FilterTypes.BUTTERWORTH, 0)
                
                # 3. Apply the band-stop (notch) filter for 50, 60 Hz noise.
                DataFilter.perform_bandstop(eeg_plot_data[i], sampling_rate, 48, 52, 3, FilterTypes.BUTTERWORTH, 0)
                DataFilter.perform_bandstop(eeg_plot_data[i], sampling_rate, 58, 62, 3, FilterTypes.BUTTERWORTH, 0)
                
                #4 High Pass above 0.5 Hz
                DataFilter.perform_highpass(eeg_plot_data[i], sampling_rate, 0.5, 4, FilterTypes.BUTTERWORTH, 0)
                
                #5. More cleaning data up
                #DataFilter.perform_rolling_filter(eeg_plot_data[i], 3, AggOperations.MEDIAN.value)
                DataFilter.perform_rolling_filter(eeg_plot_data[i], 3, AggOperations.MEDIAN.value)
                
        # --- Manual Time Axis Generation (for True Scrolling) ---
        time_vector_full_window = np.linspace(-SECONDS_TO_DISPLAY, 0, window_size)
        time_vector_for_plot = time_vector_full_window[-num_points:]
        
        for i, (line, ax) in enumerate(zip(lines, axes)):
            channel_data = eeg_plot_data[i]
            
            # Check for invalid filter output (NaN) to prevent crashes
            if np.isnan(channel_data).any():
                print(f"Warning: NaN detected in channel {eeg_channels[i]} after filtering. Skipping one update.")
                continue
            
            centered_data = channel_data - np.mean(channel_data)
            
            line.set_data(time_vector_for_plot, centered_data)
            
            # --- Adaptive Y-Axis Logic ---
            # Define how many recent samples to use for auto-scaling (last 4 seconds)
            samples_for_scaling = int(4.0 * sampling_rate)
            recent_data = centered_data[-samples_for_scaling:]
            
            if recent_data.size > 0:
                max_val = np.max(recent_data)
                min_val = np.min(recent_data)
            else:
                max_val = np.max(centered_data)
                min_val = np.min(centered_data)
                
            if np.isclose(max_val, min_val):
                max_val += 1; min_val -= 1
                
            target_max = max_val * Y_AXIS_PADDING_FACTOR
            target_min = min_val * Y_AXIS_PADDING_FACTOR
            current_min, current_max = y_limits[i]
            smoothing_factor = 0.1
            new_max = current_max * (1 - smoothing_factor) + target_max * smoothing_factor
            new_min = current_min * (1 - smoothing_factor) + target_min * smoothing_factor
            ax.set_ylim(new_min, new_max)
            y_limits[i] = (new_min, new_max)

    except Exception as e:
        print(f"!!! ERROR IN UPDATE_PLOT: {e}")

if __name__ == "__main__":
    main()
```

# 📘 Part 3: How It Works (High-Level Overview)

*Please view full setup instructions PDF for more detailed instructions on scripting.*

All BrainFlow Python scripts for this board follow a similar pattern. Here is the architecture of a session:

### 1. Initialize and Configure
*   **`params = BrainFlowInputParams()`**: Creates a configuration object. For the Cerelog board over USB, defaults are usually sufficient.
*   **`board_id = BoardIds.CERELOG_X8_BOARD`**: Selects the specific driver for our hardware.
*   **`board = BoardShim(board_id, params)`**: Creates the main controller object.

### 2. Connect and Stream
*   **`board.prepare_session()`**: Finds the board and opens the serial connection.
*   **`board.start_stream()`**: Tells the ESP32 to start collecting data into an internal buffer.
*   **`board.get_board_data()`**: Pulls the data from the buffer into a NumPy array for processing.

### 3. ⚠️ IMPORTANT: Data Scaling
Unlike consumer toys, the Cerelog board provides **raw, unscaled data** to give researchers maximum fidelity. You **must** apply scaling factors to convert these raw values into standard units.

**If you skip this, your graph will look flat **

```python
# --- 1. Scale EEG Data (Vertical Axis) ---
# The board returns data in Volts (V). Convert to microvolts (µV):
eeg_data_microvolts = eeg_data_raw * 1e6

# --- 2. Scale Timestamp Data (Horizontal Axis) [NO CHANGE NEEDED, but read]---
# The board's timestamp is unix seconds. (Firmware sends ms timestamp to Brainflow but no need to touch it because it internally converts to unix seconds. Below is in seconds!) To use and get back seconds from unix seconds:
time_axis_seconds = (timestamps_raw - timestamps_raw[0]) 
```

### 4. Advanced Real-Time Filtering
Reaching clean EEG data requires Digital Signal Processing (DSP). The raw signal contains DC offsets, mains hum (50/60Hz), and movement artifacts.

**The Filtering Chain:**
The script above implements a robust filter chain designed for real-time BCI:
1.  **Detrend:** Removes the DC offset (constant voltage drift) so the signal centers around 0 µV.
2.  **Low-Pass (100Hz):** A 4th-order Butterworth filter that removes high-frequency noise that isn't EEG.
3.  **Band-Stop (Notch):** Specifically cuts out 50Hz and 60Hz noise caused by wall outlets/mains.
4.  **High-Pass (0.5Hz):** Removes extremely slow drifts caused by sweat or head movement.
5.  **Rolling Median:** A final smoothing pass to remove sudden spikes without blurring the signal.
```

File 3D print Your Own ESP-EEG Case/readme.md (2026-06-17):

# 3D-Printed Case

STL Files located [here](https://github.com/Cerelog-ESP-EEG/3D-print-Case/tree/main)

Want a case that can hold a battery? Check this out from the community: View the print file: [here](https://www.printables.com/model/1756466-cerebrah-soft-eeg/files)

## Preview

| | | |
| :---: | :---: | :---: |
|  |  |  |
|  |  | |

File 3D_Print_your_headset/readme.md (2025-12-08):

As a cost-effective alternative, you can build your own data acquisition cap by using the 3D print files for the Ultracortex Mark III headset, a third-party project: https://github.com/OpenBCI/Ultracortex/tree/master/Mark_3

To make this headset compatible with the Cerelog ESP-EEG PCB, you must also print our special adapter plate (using the .stl file) and secure it to the headset with bolts or zip ties. The file had been included here as adaptor.stl

Note: If someone creates a case for this please email me at simon@cerelog.com, id love to include it here
I think a lot of people would benefit but didn't have enough time to cad one up

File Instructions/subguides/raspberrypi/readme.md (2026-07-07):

# DRIVER SETUP FOR Cerelog on Raspberry Pi 4B

**Get a Cerelog board running on a Raspberry Pi 4B.** Installs WCH's CH341 vendor driver so the board reliably shows up as `/dev/ttyCH341USB0` — set up once, loads automatically on every boot.





*Tested on Raspberry Pi OS (64-bit, Debian trixie), kernel `6.18.34+rpt-rpi-v8`.*

---

## What you need

| Item | Details |
| --- | --- |
| **Raspberry Pi 4B** | with SD card + USB-C power supply |
| **Monitor + USB keyboard** | monitor needs a micro-HDMI → HDMI cable/adapter |
| **Network** | an ethernet cable **or** your WiFi name + password |
| **Cerelog board** | + its USB cable |
| **A computer** | with an SD card slot (for flashing only) |

---

## Step 1 · Flash the SD card

1. On your computer, install and open **[Raspberry Pi Imager](https://www.raspberrypi.com/software/)**.
2. Choose **Raspberry Pi OS (64-bit)**, then select your SD card.
3. Click the **gear icon** (Edit Settings) and set:
   - **Username + password** — write both down
   - **Enable SSH** → password authentication
   - **WiFi** name + password (skip if using ethernet)
4. Write it, then put the card in the Pi.

> [!IMPORTANT]
> The username you pick here is your login for everything below. It does **not** default to `pi` — it's whatever you type.

---

## Step 2 · First boot

1. Plug the monitor into the Pi's **micro-HDMI port nearest the USB-C jack**, connect the keyboard, and plug in ethernet if you're using it.
2. Plug in USB-C power **last**. It boots to a desktop in under a minute.
3. If a setup wizard appears, finish it (language, WiFi, confirm user/password).
4. Open a terminal — the `>_` icon in the top bar.

Everything from here runs in that terminal.

---

## Step 3 · Build the driver

Install the build tools + kernel headers (harmless if already present):

```bash
sudo apt update
sudo apt install -y git build-essential linux-headers-rpi-v8
```

Download and build:

```bash
cd ~
git clone https://github.com/WCHSoftGroup/ch341ser_linux.git
cd ch341ser_linux/driver
make
```

> [!NOTE]
> Success ends with **"The target driver file has been generated"** and a `ch341.ko` file.

---

## Step 4 · Install the driver

```bash
sudo mkdir -p /lib/modules/$(uname -r)/kernel/drivers/usb/serial/updates
sudo cp ~/ch341ser_linux/driver/ch341.ko /lib/modules/$(uname -r)/kernel/drivers/usb/serial/updates/ch341-vendor.ko
sudo depmod -a
```

No output means it worked.

---

## Step 5 · Load it on every boot

```bash
echo "blacklist ch341" | sudo tee /etc/modprobe.d/blacklist-ch341.conf
echo "ch341-vendor" | sudo tee /etc/modules-load.d/ch341-vendor.conf
sudo reboot
```

This blocks the stock driver and auto-loads the vendor one at startup — so the board is ready straight from power-on, no manual steps.

> [!TIP]
> To undo later: `sudo rm /etc/modprobe.d/blacklist-ch341.conf /etc/modules-load.d/ch341-vendor.conf` then `sudo reboot`.

---

## Step 6 · Verify

After it reboots, plug in the Cerelog and run:

```bash
ls /dev/ttyCH341USB*
```

If you see **`/dev/ttyCH341USB0`**, you're done — the board will appear there automatically from now on.

---

## Remote access (optional)

Work on the Pi from your laptop without the monitor attached:

1. On the Pi, get its address: `hostname -I` (capital **I**) → e.g. `192.168.1.118`.
2. From your laptop: `ssh <username>@raspberrypi.local` — or use the IP: `ssh <username>@192.168.1.118`.
3. First time, type `yes` at the fingerprint prompt, then enter the **Pi's** password.

---

## Troubleshooting

| Problem | Fix |
| --- | --- |
| `make` fails about headers | Run `ls -ld /lib/modules/$(uname -r)/build` — it should point to a real path. If not, reinstall `linux-headers-rpi-v8` and retry. |
| `Unable to locate package raspberrypi-kernel-headers` | Old package name. Use `linux-headers-rpi-v8`. |
| SSH **Permission denied** | Wrong username — it's not `pi` by default. Run `whoami` on the Pi to see it. The password is the **Pi's**, not your laptop's. |
| SSH address shows `127.0.1.1` | A loopback placeholder, not the Pi. Use `hostname -I` (capital **I**) for the real address. |
| Password shows nothing as you type | Normal for terminals — just type it and press **Enter**. |

---

<sub>Driver source: [WCHSoftGroup/ch341ser_linux](https://github.com/WCHSoftGroup/ch341ser_linux)</sub>

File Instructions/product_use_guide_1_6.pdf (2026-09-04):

Need help? Should you have any issues with this setup, please email support@cerelog.com.

Having Connection Issues? Start Here

If you are having trouble getting the board to connect or stream data, check our dedicated troubleshooting repository for common fixes and debug steps:

View Troubleshooting & Debug Guide (https://github.com/Cerelog-ESP-EEG/Troubleshooting_connection/tree/main)

# Cerelog BCI/EEG Board User Guide

Welcome! This guide contains everything you need to set up, configure, and use your Cerelog 8-channel Brain Computer Interface board.

### Table of Contents

1. Critical Safety & Legal Notices
2. Prerequisites: What You'll Need
3. Hardware Overview
4. Software Setup & First Data Stream
5. Running an EEG Session
6. Advanced Usage: Firmware Customization
7. Troubleshooting Guide
8. Product Demonstrations
9. Applications & Possibilities
10. Appendix: Pinout & Technical Details

10. Appendix: Pinout & Technical Details

# 1. Critical Safety & Legal Notices

ELECTRICAL SHOCK HAZARD - READ IMMEDIATELY

This product does not have medical-grade isolation circuitry and is not protected from mains faults or power surges. To prevent risk of serious injury or death from electrical shock, you MUST adhere to the following rules:

NEVER use this device on a human subject while it is connected to a desktop computer plugged into a wall outlet.

NEVER use this device on a human subject with a laptop computer that is actively charging from a wall outlet.

ALWAYS operate this device for human data collection using a laptop running on its own battery power, or by connecting the board to an appropriate LIPO battery for power.

Evaluation Board/Kit Important Notice

Cerelog, Inc. provides the enclosed product(s) under the following conditions: This evaluation board/kit is intended for use for ENGINEERING DEVELOPMENT, DEMONSTRATION, OR EVALUATION PURPOSES ONLY and is not considered by

Cerelog, Inc. to be a finished end-product fit for general consumer use.

Persons handling the product(s) must have electronics training and observe good engineering practice standards. As such, the goods being provided are not intended to be complete in terms of required design-, marketing-, and/or manufacturing-related protective considerations, including product safety and environmental measures typically found in end products that incorporate such semiconductor components or circuit boards.

This evaluation board/kit does not fall within the scope of the European Union directives regarding electromagnetic compatibility, restricted substances (RoHS), recycling (WEEE), FCC, CE or UL, and therefore may not meet the technical requirements of these directives or other related directives.

# 2. Prerequisites: What You'll Need

### Hardware & Accessories (Not Included)

The following links point to recommended third-party vendors. Cerelog Inc. is not affiliated with these vendors and assumes no liability for their products.

Power Source: A 3.7V LIPO battery (https://www.amazon.com/2000mAh-Rechargable-Protection-Insulated-Development/dp/B0DTHG757X) is recommended for portable, untethered use. (Qty: 1, Recommended)

Data Cable: A high-quality USB-C cable rated for data transfer. (Qty: 1)

EEG Electrode Cap: (https://shop.openbci.com/products/openbci-eeg-electrocap) A professional cap for placing electrodes on the scalp. (Qty: 1)

Electrode Gel/Paste: (https://shop.openbci.com/products/electrodegel) Conductive gel for a low-impedance connection. (Qty: 1)

Touch-Proof Adapters: (https://shop.openbci.com/products/touch-proof-electrode-cable-adapter) Essential for connecting the electrode cap to the board. (Qty: 1)

IMPORTANT: Adapter & Montage

The board's default firmware is configured for Referential Montage.

This setup uses pins 1-8 (+) as the input electrodes and SRB1 as the common reference/ground.

reference/ground.

This configuration typically requires only ONE (1) touch-proof adapter to operate.

DIY Headset Alternatives
Don't have money to buy an entire headset? Make your own...

Ultracortex Mark III — 3D-Printed Rigid Cap
Third-party 3D-printed EEG cap with Cerelog adapter plate

As a cost-effective alternative, you can build your own data acquisition cap by using the 3D print files for the Ultracortex Mark III headset, (https://github.com/OpenBCI/Ultracortex/tree/master/Mark_3) a third-party project.

To make this headset compatible with the Cerelog ESP-EEG PCB, you must also print our special adapter plate (using the .stl file) and secure it to the headset with bolts or zip ties.

View Cerelog Adapter Plate Files (https://github.com/shakimiansky/ESP_EEG_Print)

The springs for the headset can be hard to find at a good price. For the soft main springs, we have found that 12mm OD, 0.6mm Wire Size, 20mm Free Length, Silver Tone springs (Size: 12x0.6x20mm) from Amazon work well.

View Recommended Springs (https://www.amazon.com/dp/B0C33CS8D9?ref=ppx_yo2ov_dt_b_fed_asin_title&th=1)

Please note: We are not affiliated with the third-party vendors who provide the Ultracortex files or the recommended springs.

CereBRAH Soft-EEG — Community-Built Soft Headband
A low-cost, DIY soft EEG headband made from nylon webbing and elastic

A community contributor designed the CereBRAH Soft-EEG — a wearable EEG headband that holds dry electrodes at standard 10-20 positions. Unlike rigid caps, it's built from 50 mm elastic band and hook-and-loop nylon webbing joined by staples, so it flexes to fit the head, packs flat, and is cheap to build and repair.

Work in progress: This project is still under active development. Designs, cut lengths, parts, and instructions may change.

View CereBRAH Soft-EEG Project Details (https://www.cerelog.com/community_cerebrah.html)

Community project — not tested or verified by Cerelog. Not a medical device.

### Software & Development Tools

A code editor, like VS Code. (https://code.visualstudio.com/)

Python (https://www.python.org/downloads/) (version 3.7 or newer).

Git (https://git-scm.com/downloads) for cloning software repositories.

For BrainFlow use:

Microsoft C++ Build Tools (https://visualstudio.microsoft.com/visual-cpp-build-tools/) (on Windows) or equivalent build essentials on Mac/Linux. CMake. (https://cmake.org/download/)

# 3. Hardware Overview

### Connecting the PCB for Data Collection

⚠
For owners of an ESP-EEG V1 — PLEASE READ!

▲ CLICK HERE TO CLOSE

EEG Setup (Scalp Recording)

SRB1 pin — This is the negative (–) reference electrode for all 8 channels. Attach an earclip electrode to one ear. Apply conductive gel under the earclip for a good connection.

BIAS pin — Attach a second earclip electrode to the other ear, also with conductive gel.

CH1+ through CH8+ — Connect these to your headset electrodes of choice. These are the only channel pins you need for a standard EEG setup.

CH1– through CH8– — Leave these unconnected. In the default firmware configuration these pins are not tied to SRB1 and are not used. Only connect them if you change the montage by editing and reflashing the firmware.

Tip: If you run into signal quality issues, give the GND pin a try in place of the BIAS pin on the second earclip — it may help.
Not Using All 8 Channels?

For best results, all 8 channels should be in use. If you are using fewer than 8

CONNECTION INSTRUCTIONS:

channels, you should either tie the unused CH+ pins to one of the active CH+ pins (connect them together physically), or disable the unused channels in the firmware (https://github.com/Cerelog-ESP-EEG/ESP-EEG/tree/main/firmware) and reflash the board. If unused channels are left floating (unconnected and enabled), the BIAS pin will be less effective at

eliminating noise, resulting in poorer signal quality across all channels.

Is your session starting out flat? Try to start the session with the GND pin connected to your earclip and then swap over to the BIAS pin once the session is running. This can help with feedback loop stabilization.

EMG Setup (Muscle Recording)

To record one channel of EMG data (e.g. forearm muscles):

CH1+ — Place on the top of the forearm (over the muscle belly).

SRB1 — Place on the bottom of the forearm as the negative (–) reference.

GND pin — Place on the elbow. For EMG, the GND pin works best as the ground reference rather than the BIAS pin.

Tip: If you experience signal issues during any recording, try swapping the BIAS pin connection for the GND pin — it can often provide better performance when signal collection problems arise.
Not Using All 8 Channels?

For best results, all 8 channels should be in use. If you are using fewer than 8 channels, you should either tie the unused CH+ pins to one of the active CH+ pins (connect them together physically), or disable the unused channels in the firmware (https://github.com/Cerelog-ESP-EEG/ESP-EEG/tree/main/firmware) and reflash the board. If unused channels are left floating (unconnected and enabled), the BIAS pin will be less effective at eliminating noise, resulting in poorer signal quality across all channels.

ESP-EEG V1 (8-Channel) — the instructions above apply to this board.

⚠
For owners of an ESP-EEG V2 & 16-Channel — PLEASE READ!

▲ CLICK HERE TO CLOSE

The board supports both a referential montage (SRB1) and a differential montage (CH+ / CH–), and you choose between them with the physical slider switch(es) on the PCB — not in software.

Choose Your Path: Set the Switch, Then Wire It

The montage is selected by the slider switch on the PCB, and the switch position determines how you wire your electrodes. Pick one of the two paths below and follow it end to end — they are mutually exclusive.

Tip: The montage switches are deliberately stiff and hard to move with your fingers. Use a sewing pin or the tip of a pencil and slide them slowly and carefully into position — do not force them. 16-Channel boards have two montage switch banks on the back of the board instead of one; both must be set to the same mode, whichever path you take.

Path A — Referential Montage (SRB1)
Best for: scalp EEG and most EMG. This is the standard mode.
1. Set the switch: move all switches to the right. This puts the board in SRB1 referential montage mode. On 16-Channel boards, set both switch banks to the right.
2. Wire your electrodes: in this mode SRB1 is the shared negative (–) reference for every channel, and BIAS drives noise cancellation. A two-channel example: CH1+ and CH2+ — connect to your two recording sites (scalp electrodes for

CONNECTION INSTRUCTIONS:

EEG, or over the muscle belly for EMG).
SRB1 — connect to one earclip electrode, with conductive gel. This is the negative (–) reference shared by both channels.
BIAS — connect to the earclip on the other ear, also with conductive gel.
CH1– through CH8– (CH16– on 16-Channel boards) — leave these unconnected in referential mode.

The same pattern scales to any number of channels: every CH+ you use goes to a recording site, SRB1 to one earclip, BIAS to the other.

CH1 is the minimum electrode that must be attached to the user. You cannot, for example, record three channels using only channels 2, 3 and 4 — one of the channels you use must physically be CH1. The BIAS pin stabilises the signal and removes noise through a feedback loop that runs through Channel 1, so without CH1 connected the BIAS circuit has nothing to work against.
For the same reason, a poor CH1 connection degrades BIAS performance across every channel. Give CH1 the best, lowest-impedance contact of all your electrodes — plenty of conductive gel and a firm, stable placement.

Path B — Differential Montage (CH+ / CH–)
Best for: measuring between two specific points, such as a single muscle in EMG.
1. Set the switch: move the switches to the opposite position (not to the right). Each channel then measures between its own CH+ and CH– pins instead of against the shared SRB1 reference. On 16-Channel boards, set both switch banks the same way.
2. Wire your electrodes:
CH1+ and CH1– — connect this pair across the two points you want to measure between. Repeat per channel: CH2+ / CH2–, CH3+ / CH3–, and so on. SRB1 — not used as the reference in this mode.
BIAS — still connect it (see the BIAS pin note below); noise cancellation works the same way in both modes.

CH1 is the minimum electrode that must be attached to the user. You cannot, for example, record three channels using only channels 2, 3 and 4 — one of the channels you use must physically be CH1. The BIAS pin stabilises the signal and removes noise through a feedback loop that runs through Channel 1, so without CH1 connected the BIAS circuit has nothing to work against.
For the same reason, a poor CH1 connection degrades BIAS performance across every channel. Give CH1 the best, lowest-impedance contact of all your electrodes — plenty of conductive gel and a firm, stable placement.

One Register to Leave As-Is: SRB1 Enable

Montage selection on V2 and 16-Channel boards is handled by the slider switch on the PCB, so the SRB1 enable bits are set in firmware to work with that switch and should be left at their default value. If you want to switch between referential and differential mode, move the switch rather than changing this register — toggling SRB1 enable in firmware will not select a montage on these boards. The rest of the firmware is yours to modify as usual.

A Note on the BIAS Pin: BIAS_EN Header & Alternative Bias Options

BIAS_EN header — must be in place (jumper installed) for the BIAS pin to work. This is the normal configuration for EEG and for most EMG.

ALT_B pin — for some niche EMG applications, ALT_B may work as an alternative bias pin. It can only be used with the BIAS_EN header removed.

GND pin — a third option worth trying for EMG. Expect worse performance than BIAS or ALT_B; its purpose is to keep the subject near the

centre of the supply so readings stay within the board's rail limits.

Optional: AVDD & AVSS Header Pins (Powering Active Electrodes)

The board exposes AVDD and AVSS header pins, which connect to the ADC supply's +2.5 V and –2.5 V inputs. If you are using ThinkPulse active electrodes, you can power them from the board's own supplies through these pins. Cerelog is not affiliated with ThinkPulse.

16-Channel Boards

Every rule above applies identically — there are simply 16 channels instead of 8, and two montage switch banks on the back of the board rather than one.

ESP-EEG V2 (8-Channel)

ESP-EEG 16-Channel

Using the SD card port on ESP-EEG V2 & 16-Channel

▲ CLICK HERE TO CLOSE

The ESP-EEG V2 and 16-Channel boards include an onboard microSD card slot,

which the original V1 board does not have. It lets you record a session directly to a card on the board instead of streaming to a computer.

Insert the Card Before You Power On

The microSD card must already be inserted before you turn the device on with the power switch. The card is detected at start-up only — inserting it after the board is powered will not start a recording.

Choosing a Card

Capacity: most cards of 32 GB or less will work, provided they are FAT32 formatted. Cards larger than 32 GB, or cards using a different file system, may not work.

Wrong format or too large? You can reformat the card with your computer's disk utility — aim for a FAT32 volume of 32 GB or under.

High-endurance cards are recommended for long recording runs. They significantly reduce the risk of file corruption or interruption over many hours of continuous writing.

What Gets Recorded

Each run produces one CSV file on the card. Every row is one sample, with the following columns:

Timestamp — milliseconds since the log started (not wall-clock time).

RECORDING TO MICROSD:

Status — the 3-byte status word emitted by the ADS1299 with every sample, written in hex. It carries the ADC's sync pattern along with lead-off and GPIO flags.

CH1 … CH8 — one column per channel, holding signed ADC counts (raw 24-bit conversion results, not volts). On 16-Channel boards this runs CH1 … CH16 instead.

So a row reads: timestamp_ms, status_hex, ch1, ch2, … ch8 (or … ch16).

Converting ADC Counts to Voltage

The channel columns are raw signed ADC counts. To convert them (V = 4.5 V, gain = 24 by default):

Verify Your Recording Before a Long Run

You are responsible for confirming that data collection is actually in progress. Before committing to a long or overnight session, do a short test run first: power the board with the card inserted, record for a minute, then check that the CSV exists on the card and contains sensible data. It is far better to catch a bad card, a bad format, or a loose electrode in a one-minute test than after eight hours of recording.

Advice on Collecting Clean Data

High-Voltage Spike Fix: If you see large voltage spikes in your data caused by environmental interference, try starting your session with the GND pin on the second earclip instead of the BIAS pin. Once the signal stabilizes, swap the earclip back to the BIAS pin — the data should return to normal. This helps the board's internal feedback loop settle and reduces environmental ringing before the BIAS-driven noise cancellation takes over.
Non-Standard Mains Frequency: The test scripts in the Cerelog test suite (including filtered_plot.py and others) have hardcoded notch-filter frequencies for 50 Hz and 60 Hz,

Terminal

scale_factor = (2 * 4.5 / 24) / (2**24) # = 2.2352e-8 V per count microvolts = raw_val * scale_factor * 1000000

REF filtered_plot.py and others) have hardcoded notch-filter frequencies for 50 Hz and 60 Hz, which covers most countries. However, if you live in a region where the power grid suffers from strong frequency instability or operates at a non-standard mains frequency, you will need to

manually edit the frequency variable in whichever test script you are using to match your local mains frequency and effectively remove that noise from your recordings.

USB-C Port: For data streaming, powering the board, and charging a connected LIPO battery.

JST-PH Battery Connector: 1.25mm pitch connector for an optional 3.7V LIPO battery.

Electrode Header Pins: Two 10-pin headers for connecting the touch-proof adapters. The SRB1 pin on the ADC is used for referential montage mode (default).

Power LED (Green): Located below the Status LED, this indicates the board is receiving power from USB or a battery.

GPIO17 Status LED (Green): This LED indicates the firmware status:

SOLID ON: Firmware has finished loading, and the board is ready to connect and stream data.
OFF: Board is not powered, or firmware has not loaded.

Battery Charge Status LED: Located to the left of the power switch (not labeled on the diagram). This LED indicates the charging status of a connected LIPO battery: RED when charging, and GREEN when fully charged.

Onboard Motor (ESP-EEG V1 only): The original V1 board has a tactile feedback motor that can be controlled via custom firmware. Note that activating it will introduce noise into EEG signals. The V2 and 16-Channel boards do not have this motor — it was removed in the newer revisions.

newer revisions.

Connecting the Battery Correctly

Carefully align the JST plug so the RED wire connects to the 'RED' (+) marking on the PCB and the BLACK wire connects to the 'BLK' (-) marking. To remove the connector, do not pull the wires; gently squeeze the plastic plug and wiggle it out of the socket.

# 4. Software Setup & First Data Stream

This section guides you through installing software to visualize your EEG data.

A Note for Beginners

The following steps require using your computer's Terminal (also called a command prompt or shell). This is a text-based way to interact with your computer. We recommend using a modern code editor like VS Code, (https://code.visualstudio.com/) which has a built-in terminal and makes it easy to view files.
Basic Terminal Commands

ls : Lists the files and folders in your current location.
cd FOLDER_NAME : Changes directory into the specified folder.
cd .. : Moves up one level to the parent folder.
Important Notes

Before running any commands to clone a repository, first use cd to navigate to a folder you can easily find, like your Desktop or Documents folder.
On macOS, Python and its package manager `pip` are often installed as `python3`

and `pip3` to distinguish them from an older, system-installed version of Python. In this guide, whenever you see python or pip , use python3 and pip3 if you are on a Mac.
To stop a script that is running in the terminal, press Ctrl + C (on Windows/Linux) or Cmd + C (on Mac).

Note: Device refuses to connect? Read this helpful troubleshooting guide. (https://github.com/Cerelog-ESP-EEG/Troubleshooting_connection/tree/main)

### Step 1 (Optional): Install Drivers if Needed

Note: This step applies to V1 devices only. V2 and 16-Channel boards do not require driver installation.

Modern operating systems like Windows 10/11 and recent versions of macOS/Linux should recognize the board automatically. Only follow this step if your computer fails to detect the board or assign it a COM port.

Install CH340C USB-to-Serial Drivers (V1.3 only)

If needed, install the CH340C chipset driver. Follow the SparkFun guide linked below for step-by-step instructions for your operating system.

CH340 Driver Installation Guide (SparkFun) (https://learn.sparkfun.com/tutorials/how-to-install-ch340-drivers/all#drivers-if-you-need-them)

Also: Linux Users May Need the CH341SER Driver

If the CH340C driver above still doesn't work, try the CH341SER driver instead (this is a separate driver from the CH340C linked above). This usually works better for Linux and can often fix issues with the board not connecting.

Download CH341SER Driver (https://www.wch-ic.com/downloads/CH341SER_EXE.html)

Note: If you decide to use the CH341SER driver, you may need to hardcode the

port names in your BrainFlow test scripts and LSL linking script. Read here for instructions on hardcoding port names. (https://github.com/Cerelog-ESP-EEG/Troubleshooting_connection/blob/main/manual_connect/readme.md)

Raspberry Pi Users: Driver Setup Required

If you own a Raspberry Pi, you will need to complete an additional driver setup step before the board can connect. Follow the guide linked below for full instructions.

Raspberry Pi Driver Setup Guide (https://github.com/Cerelog-ESP-EEG/ESP-EEG/blob/main/Instructions/subguides/raspberrypi/readme.md)

Debug Step: Hardcoding Port Names

Some computers assign unusual or unexpected port names to the device. If automatic detection fails, you will need to hardcode the exact port name into your test script.

Read the manual port connection guide here. (https://github.com/Cerelog-ESP-EEG/Troubleshooting_connection/blob/main/manual_connect/readme.md)

For additional debug help, see the full Troubleshooting & Debug Guide. (https://github.com/Cerelog-ESP-EEG/Troubleshooting_connection/tree/main)

### Step 2: Choose and Configure Your Visualization Method

## Method A: Using the BrainFlow Library

(Recommended / Advanced) This involves building our custom fork of the BrainFlow library from source. This compilation is a one-time setup for your computer. Because the core library is written in C++, it must be compiled specifically for your operating system (Windows, Mac, or Linux). You only need to repeat the build process (Step A.2) if you modify the underlying C++ source code files (.cpp, .h). Creating new Python

scripts does not require a rebuild.

A.1: Get the Custom BrainFlow Fork

Our board requires a specific fork of BrainFlow. Clone it and navigate into the new directory:

Important: Use This Specific Repository

This version of BrainFlow contains code specific to the Cerelog board. This code has not yet been merged into the official, main BrainFlow repository. You must use the link provided below.

Terminal

git clone https://github.com/shakimiansky/Shared_brainflow-cerelog.git

Terminal

cd Shared_brainflow-cerelog

A.2: Build the Library from Source

This crucial step compiles the C++ core of the library. If you make a mistake, manually delete the `build` folder and start this step over.

macOS and Raspberry Pi Users: Install Build Tools First

macOS: Install Homebrew (a package manager) and CMake. Open a terminal and run the following commands one by one:

Terminal

brew install cmake

Raspberry Pi (Linux): Raspberry Pi OS uses apt instead of Homebrew. Install CMake by running:

Terminal

sudo apt install cmake

Compilation Steps:
First, create a new directory named `build` inside the `Shared_brainflow-cerelog` folder and navigate into it.

Terminal

mkdir build

Terminal

cd build

Terminal

/bin/bash -c "$(curl -fsSL https://raw.githubusercontent.com/Homebrew/install/HEAD/install.sh)"

Next, run the correct `cmake` command for your operating system to prepare the build files.

For Windows (with Visual Studio 2022):

Terminal

cmake .. -G "Visual Studio 17 2022" -A x64

For macOS / Linux:

Terminal

cmake ..

Finally, run the build command. This uses 4 processor cores (`-j4`) for faster compilation; you can adjust this number.

Terminal

cmake --build . --config Release --clean-first -j4 -- -k

A.3: Install the Python Package

Raspberry Pi Users: Create a Virtual Environment First

Raspberry Pi OS requires you to use a Python virtual environment before installing packages. Run these commands before proceeding with the steps below:

Terminal

python3 -m venv ~/cerelog-venv

Terminal

source ~/cerelog-venv/bin/activate

You will need to re-activate the virtual environment with source ~/cerelog-venv/bin/activate each time you open a new terminal session.

With the core library built, navigate from the `build` folder back up and into the Python wrapper folder.

Terminal

cd ..

Terminal

cd python_package

Install the package in "editable" mode. (Remember to use pip3 on Mac). This links the package to the source files, so you don't need to reinstall after making changes. This command only needs to be run once to set up your environment.

Terminal

pip install -e .

A.4: Install Required Python Libraries

Before running any scripts, install the required Python libraries. Run the command below. (Use pip3 on Mac).

Terminal

pip install matplotlib pyserial plotly dash scikit-learn "setuptools<82"

If the command above fails, install them one at a time:

Terminal

pip install matplotlib

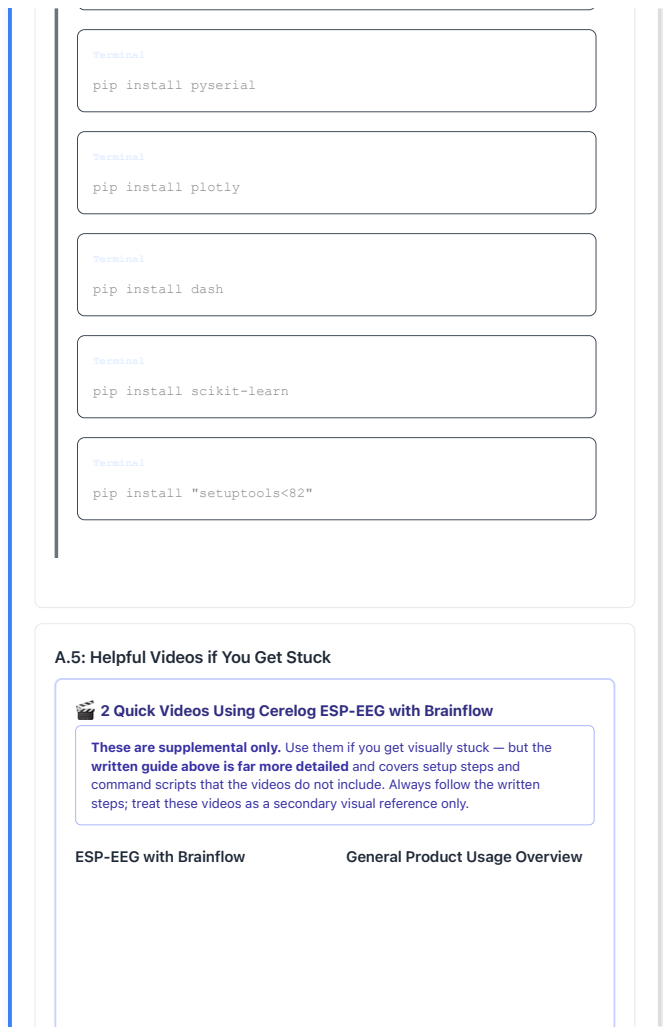
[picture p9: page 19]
ESP-EEG with Brainflow; General Product Usage Overview

Terminal
pip install pyserial

pip install plotly

pip install dash

pip install scikit-learn

pip install "setuptools<82"

A.5: Helpful Videos if You Get Stuck

2 Quick Videos Using Cerelog ESP-EEG with Brainflow

These are supplemental only. Use them if you get visually stuck — but the
written guide above is far more detailed and covers setup steps and
command scripts that the videos do not include. Always follow the written
steps; treat these videos as a secondary visual reference only.

These videos do not cover all setup command scripts. Always refer to the written guide above for the complete setup procedure.

Keep scrolling! The setup guide continues below — this section is not finished yet.

Click to Expand: Learning How to Write and Filter BrainFlow Data

Once you have BrainFlow installed, you can write your own Python scripts to control the board and acquire data. This section provides a complete learning path, starting from a basic script and moving to advanced real-time filtering.

### Part 1: Understanding Data Scaling & Basic Scripting

To write your own applications, we recommend studying the example script below in combination with the unix_plot.py test script found in the repository. For in-depth information on functions, consult the official BrainFlow documentation. (https://brainflow.readthedocs.io/en/stable/)

1. Basic Example: Stream & Static Plot

Save the code below as a new file, for example my_plot_test.py , inside the test folder you used previously: Shared_brainflow-

cerelog/python_package/cerelog_tests . Then run it from the terminal.

Terminal

import time
import numpy as np
import matplotlib.pyplot as plt

from brainflow.board_shim import BoardShim, BrainFlowInputParams, BoardIds, BrainFlowError

def main():
"""
A simple script to connect to a BCI, collect data for a few seconds, and then plot the EEG data.
"""
# Board and acquisition parameters

board_id = BoardIds.CERELOG_X8_BOARD duration_seconds = 10

# --- 1. SETUP THE BOARD ---

# BrainFlow uses a params object to configure the board

# BrainFlow uses a params object to configure the board params = BrainFlowInputParams()

# Create the BoardShim object

board = BoardShim(board_id, params)

# Use a try/finally block to ensure session is always released try:

# Get board info using static methods

eeg_channels = BoardShim.get_eeg_channels(board_id) timestamp_channel = BoardShim.get_timestamp_channel(board_id) sampling_rate = BoardShim.get_sampling_rate(board_id)

print(f"Connecting to {board.get_board_descr(board_id)['name']}...") print(f"EEG Channels: {eeg_channels}")
print(f"Sampling Rate: {sampling_rate} Hz")

# Prepare the session (finds the board and establishes connection) board.prepare_session()

# --- 2. ACQUIRE DATA ---

print(f"\nStarting stream for {duration_seconds} seconds...") board.start_stream()
time.sleep(duration_seconds)

# Stop the stream and get the data from the internal buffer board.stop_stream()

print("Stream stopped. Getting data...")
data = board.get_board_data()

if data.size == 0:
print("Error: No data was collected.") return

# --- 3. PROCESS AND PLOT DATA ---

# Get the specific data streams from the data array eeg_data = data[eeg_channels]

timestamps = data[timestamp_channel]

# Create a time axis starting from 0 time_axis = timestamps - timestamps[0]

print("Plotting data...")
plt.figure(figsize=(15, 8))

# Plot each EEG channel with a vertical offset for clarity offset_value = 150 # µV

for i, channel_data in enumerate(eeg_data):

How It Works: A High-Level Overview

All BrainFlow Python scripts follow a similar pattern:

1. Import Libraries: You always need BoardShim and BrainFlowInputParams. For this example, we also import BoardIds to select our board, time for pausing, and numpy and matplotlib for data handling and plotting.
2. Initialize and Configure:
params = BrainFlowInputParams() creates a configuration object. For the Cerelog board over USB, you don't need to set any special parameters.
board_id = BoardIds.CERELOG_X8_BOARD selects the specific board you're using from a list of supported devices.
board = BoardShim(board_id, params) creates the main board object that you'll use to control everything.
3. Get Board Info: Before connecting, you can get the board's specifications (like its sampling rate and which rows in the data array will contain EEG data) using static methods like BoardShim.get_eeg_channels(board_id). This is the best practice and makes your code more readable.

for i, channel_data in enumerate(eeg_data):
plt.plot(time_axis, channel_data + i * offset_value, label=f'Channel {eeg_channels[i]}')

# Add titles and labels for clarity

plt.title(f'{duration_seconds} Seconds of Cerelog EEG Data')
plt.xlabel('Time (s)')
plt.ylabel('Voltage (µV) - Channels are offset for clarity') plt.legend(loc='upper right')
plt.grid(True)
plt.tight_layout()

# Show the plot

plt.show()

except BrainFlowError as e:
print(f"BrainFlow Error: {e}")
except Exception as e:
print(f"An unexpected error occurred: {e}") finally:
# --- 4. CLEAN UP ---

# Always release the session to free the COM port if board.is_prepared():

print("\nReleasing session.") board.release_session()

if __name__ == "__main__": main()

4. Connect and Stream Data:
board.prepare_session() finds the board and opens the connection. board.start_stream() tells the board to start collecting data into an internal buffer.
time.sleep(...) pauses your script to let data collect in the buffer. board.stop_stream() stops the collection.
5. Retrieve and Index Data:
data = board.get_board_data() retrieves all the data from the buffer as a 2D NumPy array.
The `data` array has a specific structure. Each row represents a different channel. By using the channel arrays you fetched in step 3, you can easily select the correct rows: eeg_data = data[eeg_channels] for the EEG data, and time_data = data[timestamp_channel] for the timestamps.
For advanced users: If you wish to hardcode the indices, the data array for the Cerelog board is typically organized as follows, though using the `get...` methods is strongly recommended:
Row 0: Packet Counter
Rows 1-8: EEG Channels
Row 9: Marker Channel
Row 10: Timestamp Channel
6. Clean Up: Always call board.release_session() in a `finally` block. This ensures the connection to the board is closed properly, freeing up the COM port for other applications.

IMPORTANT: Scaling Cerelog Data in BrainFlow

Unlike some other devices, the Cerelog board provides raw, unscaled voltage data to give you maximum fidelity and control. When processing this data in your own BrainFlow scripts, you must apply a scaling factor to convert the raw voltage values into standard units.

Failure to apply the voltage conversion will result in incorrect plots and analysis, with a flat-looking vertical (voltage) scale.
Required Data Conversions:

Inside your data processing loop or after you retrieve data with board.get_board_data() , apply the following:

Terminal

# Get the raw data streams from the main data array eeg_data_raw = data[eeg_channels]

timestamps_raw = data[timestamp_channel]

# --- 1. Scale EEG Data (Vertical Axis) ---

# The board returns data in Volts (V). To get microvolts (µV), # the standard unit for EEG, you must multiply by 1,000,000.

Always use the scaled variable eeg_data_microvolts for your plotting and analysis functions. The timestamp data does not need to be scaled — BrainFlow handles the conversion to seconds automatically.

### Part 2: Advanced Real-Time Filtering

Reaching clean EEG data requires more than just connecting to the board. You must apply digital signal processing (DSP) to remove noise and isolate the brainwaves. While the basic test above shows you how to stream, we recommend using the script below ( filtered_plot.py ) as your main reference for creating robust applications.

Understanding the Filters

The code below implements a chain of filters crucial for real-time BCI. Here is what they do:

1. Detrend: Removes the DC offset (the constant voltage drift) so the signal centers around 0 microvolts.

Terminal
DataFilter.detrend(eeg_plot_data[i], DetrendOperations.CONSTANT.value)
2. Low-Pass (100Hz): Removes high-frequency noise that isn't EEG. We use a 4th-order Butterworth filter for stability in real-time streams.

Terminal
DataFilter.perform_lowpass(eeg_plot_data[i], sampling_rate, 100.0, 4, FilterTypes.BUTTERWORTH, 0)
3. Band-Stop (Notch Filters): Specifically targets 50Hz and 60Hz noise

# the standard unit for EEG, you must multiply by 1,000,000. eeg_data_microvolts = eeg_data_raw * 1e6

# --- 2. Timestamp Data (Horizontal Axis) ---

# The board sends timestamp data in milliseconds, but BrainFlow

# automatically converts it to Unix time in seconds. No additional # scaling is needed. Simply make it relative to the start time. time_axis_seconds = timestamps_raw - timestamps_raw[0]

3. Band-Stop (Notch Filters): Specifically targets 50Hz and 60Hz noise caused by electrical mains (wall outlets).

Terminal
DataFilter.perform_bandstop(eeg_plot_data[i], sampling_rate, 48, 52, 3, FilterTypes.BUTTERWORTH, 0) DataFilter.perform_bandstop(eeg_plot_data[i], sampling_rate, 58, 62, 3, FilterTypes.BUTTERWORTH, 0)
4. High-Pass (0.5Hz): Removes extremely slow drifts caused by movement or sweat.

Terminal
DataFilter.perform_highpass(eeg_plot_data[i], sampling_rate, 0.5, 4, FilterTypes.BUTTERWORTH, 0)
5. Rolling Median: A final smoothing pass that helps remove sudden spikes without blurring the signal as much as a mean filter would.

Terminal
DataFilter.perform_rolling_filter(eeg_plot_data[i], 3, AggOperations.MEDIAN.value)
2. Advanced Example: Real-Time Filtering & Scrolling

Save the code below as filtered_plot.py and run it.

ax.set_ylabel('Voltage (µV)')

ax.grid(True)
ax.set_xlim(-SECONDS_TO_DISPLAY, 0)

fig.text(0.5, 0.04, 'Time (Seconds from "Now")', ha='center', va='center') plt.tight_layout(rect=[0, 0.05, 1, 0.96])

def on_close(event):
print("Plot window closed, stopping stream...") if board and board.is_prepared(): board.stop_stream()
board.release_session()
print("Session released. Exiting.")

fig.canvas.mpl_connect('close_event', on_close)

ani = FuncAnimation(fig, update_plot, fargs=(lines, axes_flat), interval=UPDATE_INTERVAL_MS, blit=False)

A.6: Run Included Tests

Wait for the Green LED!

Before running any test that connects to the board, make sure you've plugged it in and waited for the green GPIO17 status LED to turn solid on. This indicates the firmware has loaded and the board is ready to stream.

The repository includes a comprehensive test suite. To run them, you must be inside the python_package directory.

1. Recommended First Test: Visual Data Stream
We strongly recommend running the Filtered Plot test first. This script provides a

real-time, filtered graph of all 8 channels, allowing you to instantly verify signal quality and electrode contact.

Raspberry Pi Users: Read This First

1. Activate Your Virtual Environment

Before running any test scripts, make sure your virtual environment is active. If you opened a new terminal since Step A.3, re-activate it:

Terminal

source ~/cerelog-venv/bin/activate

2. Hardcode the Serial Port

All BrainFlow test scripts — including filtered_plot.py — must ani = FuncAnimation(fig, update_plot, fargs=(lines, axes_flat), interval=UPDATE_INTERVAL_MS, blit=False) plt.show()

except Exception as e:

All BrainFlow test scripts — including filtered_plot.py — must have the serial port name hardcoded to run on Raspberry Pi. Automatic port detection does not work on Pi.

In each script, find the line:

Terminal

params = BrainFlowInputParams()

And add the following line directly after it:

Terminal

params.serial_port = "/dev/ttyCH341USB0"

You must make this edit in every BrainFlow test script you want to run on the Pi.

3. Running Test Scripts Over SSH

Test scripts that display plots must be run from the Raspberry Pi's own terminal. If you are connected over SSH, the plot window cannot open on your remote machine by default. To run a script over SSH and have the plot display on the Pi's screen, prefix the command with DISPLAY=:0 :

Terminal

DISPLAY=:0 python filtered_plot.py

Terminal

cd cerelog_tests

Terminal

python filtered_plot.py

Did you get: ModuleNotFoundError: No module named 'pkg_resources'?

'pkg_resources'?

This is because your version of setuptools has removed this legacy module. To fix it, downgrade setuptools by running:

Terminal

python3 -m pip install "setuptools<82"

On Windows, use python instead of python3 :

Terminal

python -m pip install "setuptools<82"

Note: Device refuses to connect? Read this helpful troubleshooting guide. (https://github.com/Cerelog-ESP-EEG/Troubleshooting_connection/tree/main)

2. Run PCB Health Check Suite
To verify the technical integrity of the board (timestamps, packet loss, serial connection), run the automated test suite.

Terminal

python run_all_tests.py

Key Tests Explained

test_brainflow.py
The best starting point for developers. It demonstrates the full cycle: connecting to the board, streaming data, and calculating basic stats. It also saves the raw data to a CSV file.

unix_plot.py
Highly recommended test. This script connects to the board, streams data, and provides a real-time plot, making use of the board's Unix timestamps for accurate timing.

test_serial.py
A low-level test that bypasses BrainFlow to communicate directly with the board. Use this if you suspect a fundamental serial connection or packet format issue.

test_unix_timestamps.py
An advanced test for verifying time synchronization between the board and

your PC, crucial for time-sensitive experiments.

For a complete list of tests and advanced debugging options, please see the `README.md` file inside the `cerelog_tests` directory.

A.7: Play BCI Pong (New)

### EPILEPSY & LIABILITY WARNING

Games contained in this software repository may contain flickering lights or flashing patterns which can trigger seizures in individuals with photosensitive epilepsy. By choosing to run these games, you acknowledge these risks. You agree to hold Cerelog Inc. and all affiliated parties harmless from any liability or damages that may arise from their use.

Once you have installed the BrainFlow library (Steps A.1 through A.3), you can play the new BrainFlow-enabled Pong game.

Performance Requirement

This game uses SSVEP (Steady-State Visually Evoked Potential) which relies on high-frequency flickering lights. It will not work properly on slow computers because the screen cannot refresh fast enough to create the required brain stimulation frequencies.

To play, navigate to the games folder inside the Python package:

Terminal

cd Games/"Fancy JS Game"

Run the game script (remember to use python3 on Mac):

Terminal

python pong_game_brainflow.py

Note: You may find other games in the Games directory that are currently under development.

### Method B: Legacy Python Web Plotter (Deprecated)

This method is outdated and no longer recommended. Click to expand if needed.

This method uses a Python script to stream data to a real-time plot in your web browser. It is less stable than Method A.

B.1: Get the Code

In your terminal, navigate to a memorable folder (like Desktop). Then, clone the repository containing the script.

Terminal

git clone
https://github.com/shakimiansky/Shared_Cerlog_ESP_EEG_BCI.git

B.2: Install Libraries

First, navigate into the folder you just cloned.

Terminal

cd Shared_Cerlog_ESP_EEG_BCI

Now, install the required Python packages. (Remember to use pip3 on Mac).

Terminal

pip install numpy pyserial plotly dash scikit-learn

B.3: Run & View

Navigate into the Python displayer subfolder.

Terminal

cd PythonEasyDisplay

Run the script. It will automatically find the board and print a URL. Open this link in your browser to see the data. (Remember to use python3 on Mac).

Wait for the Green LED!

After plugging in the board, wait a few seconds for the green GPIO17 status LED to turn solid on. This indicates the firmware has loaded and the board is ready. The script will only be able to connect after this LED is lit.

Terminal

python Python_Data_Displayer.py

# 5. Running an EEG Session

1. Hardware Assembly: Connect your EEG cap cable(s) to the required touch-proof adapter(s), then plug the adapter(s) into the electrode headers on the Cerelog board.
2. Prepare the Subject: Fit the EEG cap on the subject's head. Apply a small amount of conductive gel into each electrode cavity to ensure good skin contact.
3. Connect Reference & Bias (Ear Clips): For accurate BCI data collection, you must use two ear clip electrodes with conductive gel.

Connect the first ear clip to the BIAS pin.

Connect the first ear clip to the BIAS pin.
Connect the second ear clip to the SRB1 pin (this acts as the Ground/Reference in the default montage).
Attach one clip to each earlobe.
4. Connect and Stream: Connect the board to your computer via USB-C. Launch your chosen software or script, and start the data stream.

Safety Reminder

As per the notice in Section 1, only connect to a laptop running on its own battery power. **DO NOT** use this device if the laptop is charging or connected to a desktop computer plugged into a wall outlet.

5. Check Signal Quality: Observe the incoming data. If a channel is flat or excessively

noisy, check the corresponding electrode's position and consider re-applying a small amount of gel.

IMPORTANT: Signal Quality & Artifacts

The human body acts like an antenna, picking up the 50/60 Hz hum from nearby electrical mains. This noise is often much stronger than the tiny EEG signals from the brain. Getting a clean signal is critical for any BCI application.
1. Effective Filtering & "Jaw Clench" Artifacts

The Cerelog board utilizes highly effective filtering on the BIAS pin to cancel out common-mode noise. Because of this superior noise cancellation, you might not see massive, screen-filling spikes when you clench your jaw, unlike on some cheaper or older hardware. This is normal. It means the board is successfully filtering out the noise generated by the muscle movement, allowing the EEG signal to remain cleaner.
2. Use the Bias Probe Correctly

The **BIAS probe** is the single most important tool for noise cancellation. It measures the mains hum from the body and subtracts it from the EEG channels. You will get poor data without it. Ensure the ear clips used for BIAS and SRB1 have plenty of conductive gel.
3. Filter Your Data

3. Filter Your Data

For best results, especially with BrainFlow, we highly recommend applying a **notch filter** to your data in software to remove any remaining 50 Hz or 60 Hz noise.

# 6. Advanced Usage: Firmware Customization

Firmware Access is Restricted

To receive the firmware source code or if you need the code to change montages, please

email support@cerelog.com with your proof of purchase (e.g., order number). Firmware can be modified and flashed using the Arduino IDE.

### WARNING: Custom Firmware & Software Compatibility

Any modifications you make to the firmware are **not guaranteed to work** with the provided BrainFlow fork, Python plotter, or games. Changes to critical parameters like sample rate, data resolution, or packet structure **will** break the software.

If you modify the firmware, you may be required to make heavy modifications to the software to maintain compatibility. This is an advanced task and is your own responsibility.

Configuring the Arduino IDE

Before flashing, you must configure the IDE with the correct settings:

Board: Navigate to Tools > Board > ESP32 Arduino and select **'ESP32 WROOM DA Module'**.
Port: Navigate to Tools > Port and select the COM port corresponding to your Cerelog board.

Modifying the firmware is necessary to:
Change Electrode Montage: Switch from the default Referential mode to Sequential mode. Sequential mode measures the difference between P and N pins directly, requiring two adapters.

adapters.

Adjust Gain: Change the Programmable Gain Amplifier (PGA) setting (1, 2, 4, 6, 8, 12, or 24).

Control Peripherals: Write custom code to use the debug LEDs, or—on V1 boards only— the haptic feedback motor. The V2 and 16-Channel boards do not have a motor.

Change Sample Rate: This is a highly advanced modification. Altering the sample rate or resolution will change the data stream format and will require you to rewrite the data parsing

logic in your software.

CRITICAL: Procedure After Flashing Firmware

1. After a successful flash, you MUST perform a full power cycle. Unplug the USB-C cable. If a battery is connected, unplug it as well.
2. Reconnect the power (USB-C and/or battery).
3. Your computer may assign the board a new COM port number. Check your Device Manager to see the new port assignment.
4. When you run your software again, both the Python plotter and a properly configured BrainFlow script should find the new port automatically. If you have hard-coded a specific COM port in a custom script, you will need to update it manually.

# 7. Troubleshooting Guide

Problem: Board not detected (no COM port appears).

- First, try a different USB port and ensure you are using a USB-C data cable, not a charge-only one.
- If it's still not detected, proceed with the optional CH340C driver installation in Section 4.
- Check for the green power LED on the board. If it's not on, there is a power issue.

Problem: My script fails to connect.

- Make sure (https://www.cerelog.com/) the green status LED is on before running your script. This indicates the (https://www.cerelog.com/eeg_researchers.html) firmware is (https://www.cerelog.com/) loaded and ready.
- Try a full power cycle. Disconnect the USB-C cable, wait a few seconds, and plug it back in before re-running your script.
- Make sure no other program is already connected to the board's COM port. Only

Back to Product Page (https://www.cerelog.com/eeg_researchers.html)

- Make sure no other program is already connected to the board's COM port. Only

one application can use the port at a time.
- If you recently flashed new firmware, see the "Procedure After Flashing" notes in Section 6.

Problem: Data is extremely noisy or flat.

- Poor electrode connections are the most common cause of bad signal quality. Ensure that all electrodes, especially the **BIAS probe**, have a secure, low-impedance connection.
- Ensure you are not near sources of high electromagnetic interference (e.g., power bricks, fluorescent lights, powerful fans).
- Re-apply conductive gel to the problematic electrodes.

# 8. Product Demonstrations

See the Cerelog ESP-EEG board in action. These demos showcase the real-time data streaming and BCI control capabilities.

### Product Demos

See the Cerelog ESP-EEG board in action. These demos showcase the real-time data streaming and BCI control capabilities.

Product Overview Guide and Live Data Visualization

Video demonstrating how to use product for real-time EEG signal data streaming and plotting.

# 9. Applications & Possibilities

This board is a versatile tool for developers and researchers. With custom software, you can explore a wide range of applications.

Multimodal Signal Acquisition: Capture data for EEG (brain), EMG (muscle), ECG (heart), and EOG (eye movement).

Neuroscience Paradigms: Design experiments based on P300, Event-Related Potentials (ERP), and Steady-State Visually Evoked Potentials (SSVEP).

BCI & Control Systems: Develop systems to quantify cognitive or emotional states, or to control robotics and other external devices.

# 10. Appendix: Technical Details

### Technical Specifications

Input Channels | 8 differential channels + 1 bias probe input
ADC | Texas Instruments ADS1299
ADC Resolution | 24-bit
Sample Rate | 250 SPS (default, firmware configurable)
Programmable Gain | 1, 2, 4, 6, 8, 12, 24 (firmware configurable)

Connectivity USB-C (data/power). Note: WIFI & Bluetooth hardware is present, but software is under
| development and not yet available.

development and not yet available.

### Understanding Electrode Montages

The board can be configured in two primary ways:

Referential Montage (Default): Each channel measures the potential difference between a positive input (Pins 1-8+) and a common reference. In this mode, the SRB1 pin is configured as the common ground/reference for all channels. This configuration is standard for most BCI applications and typically requires only a single 10-pin adapter.

Sequential / Bipolar Montage (Requires Firmware Mod): Each channel measures the potential difference between a positive input (INxP) and a negative input (INxN). For example, Channel 1 is (IN1P - IN1N). This requires two 10-pin adapters to connect all necessary pins.

A Note on Performance

The core of this board is the research-grade TI ADS1299 ADC. While the chip has exceptional theoretical performance (capable of resolving ~10µV signals), real-world board performance will be influenced by your setup, environmental noise, and electrode contact quality. For complete details on the ADC, see the official TI ADS1299 Datasheet. (https://www.ti.com/lit/ds/symlink/ads1299.pdf)

Twitter (https://twitter.com/CerelogOfficial) LinkedIn (https://linkedin.com/company/cerelog)

© 2025 Cerelog Inc. All rights reserved.

For support or firmware requests, please contact support@cerelog.com.

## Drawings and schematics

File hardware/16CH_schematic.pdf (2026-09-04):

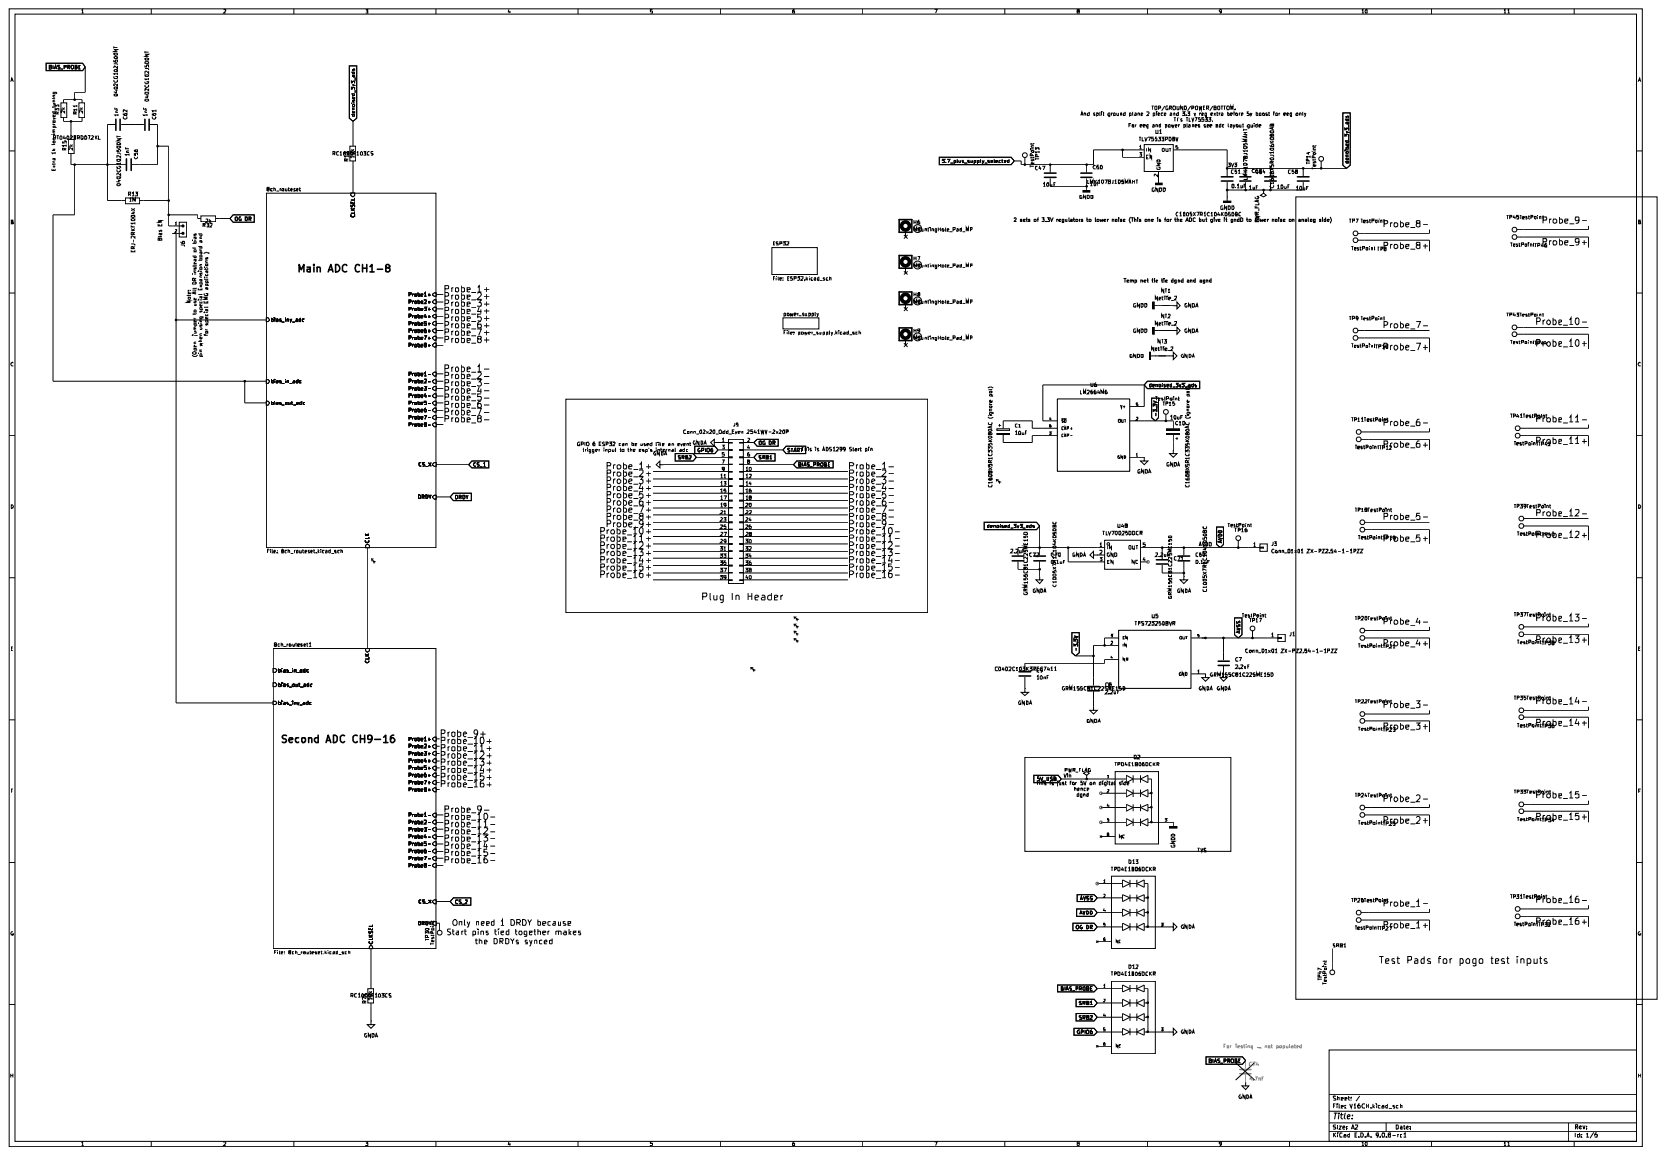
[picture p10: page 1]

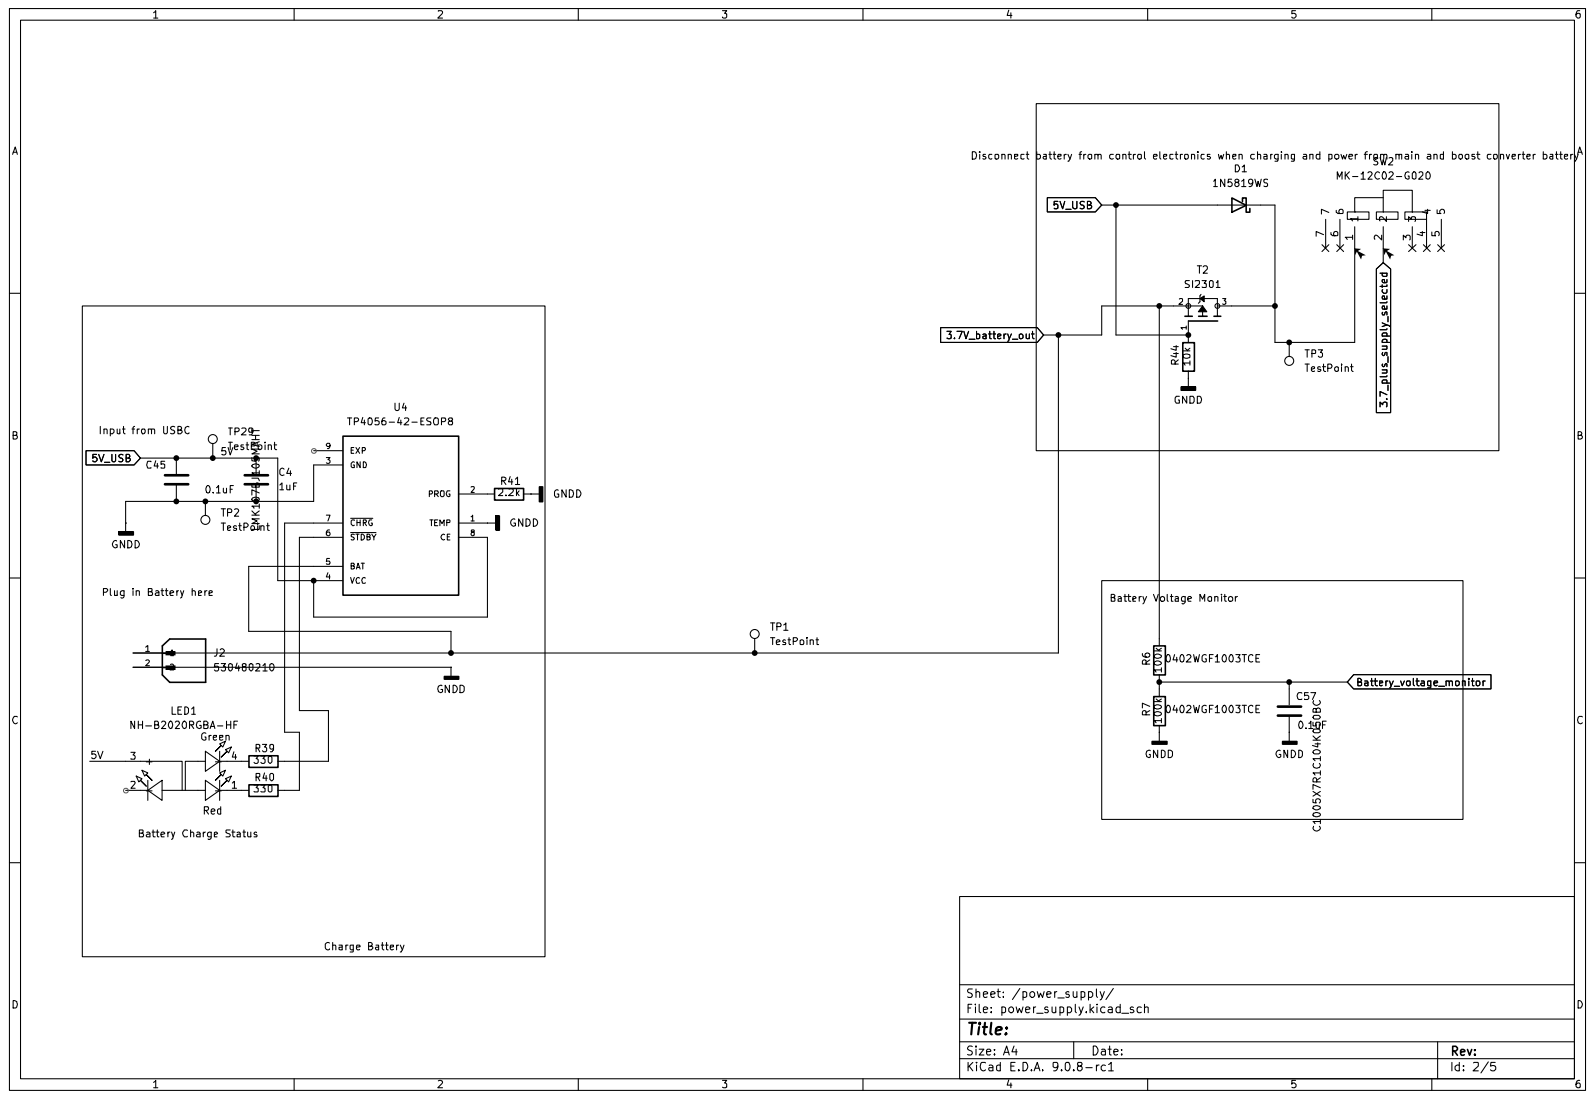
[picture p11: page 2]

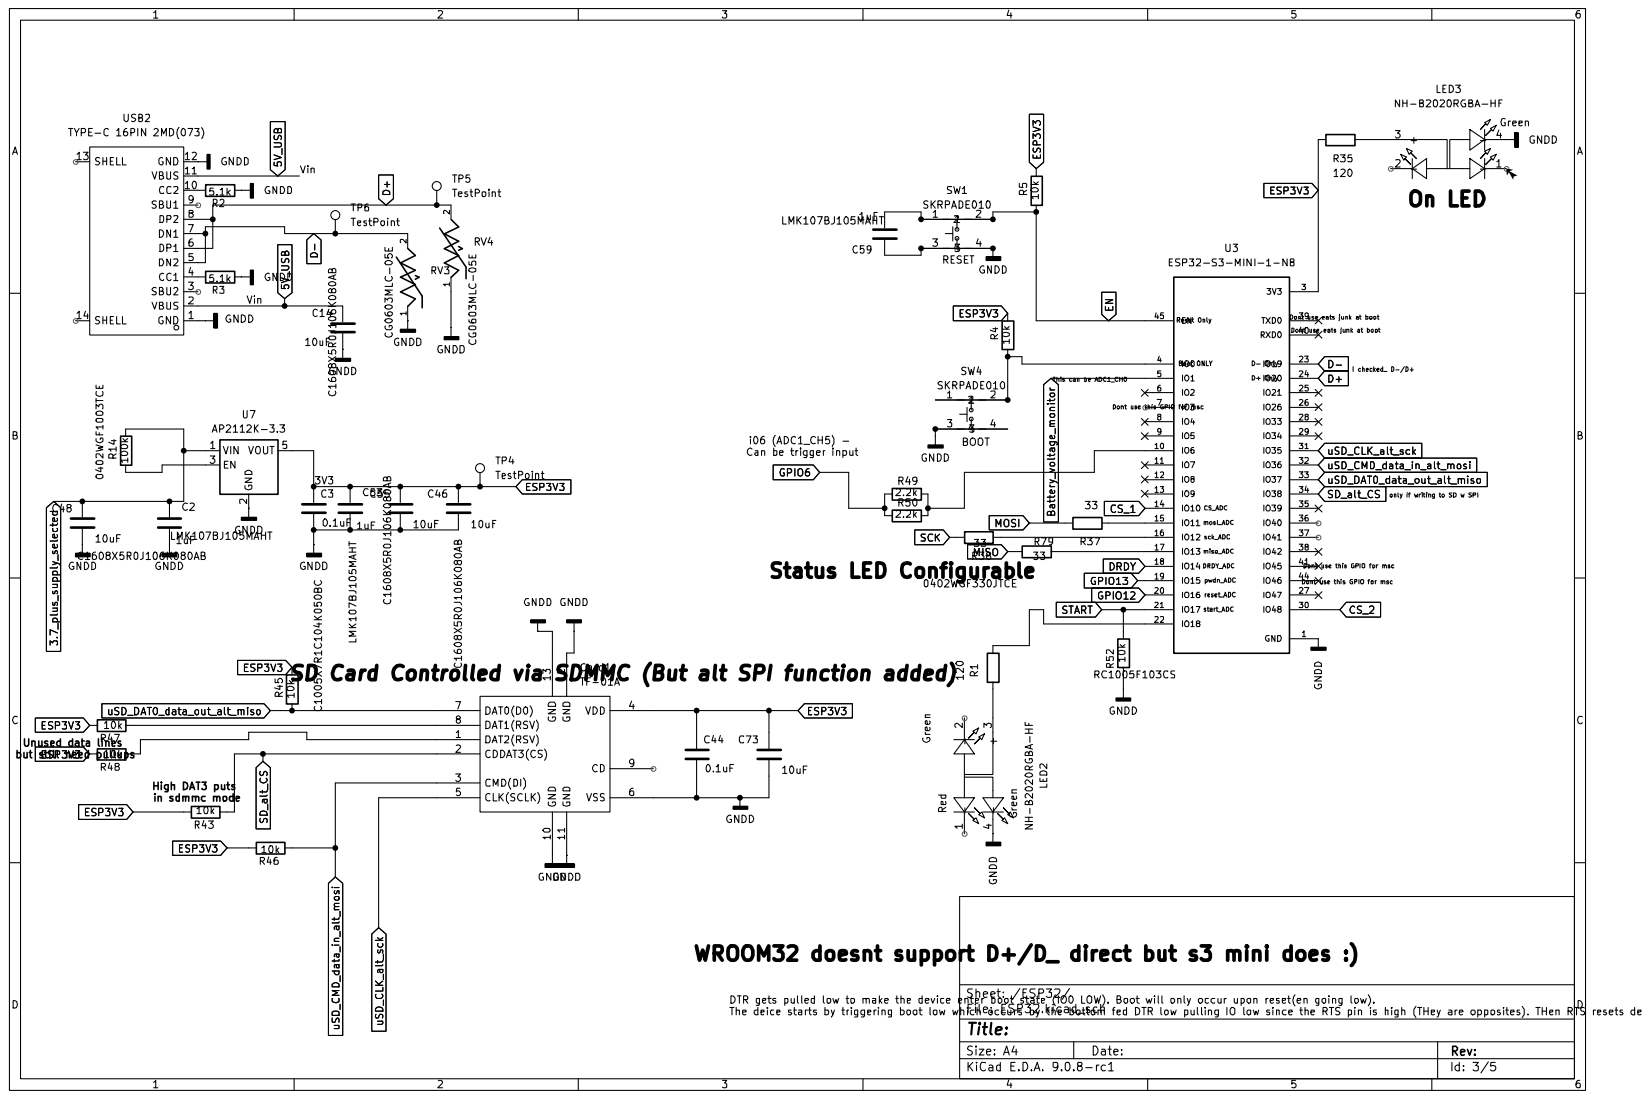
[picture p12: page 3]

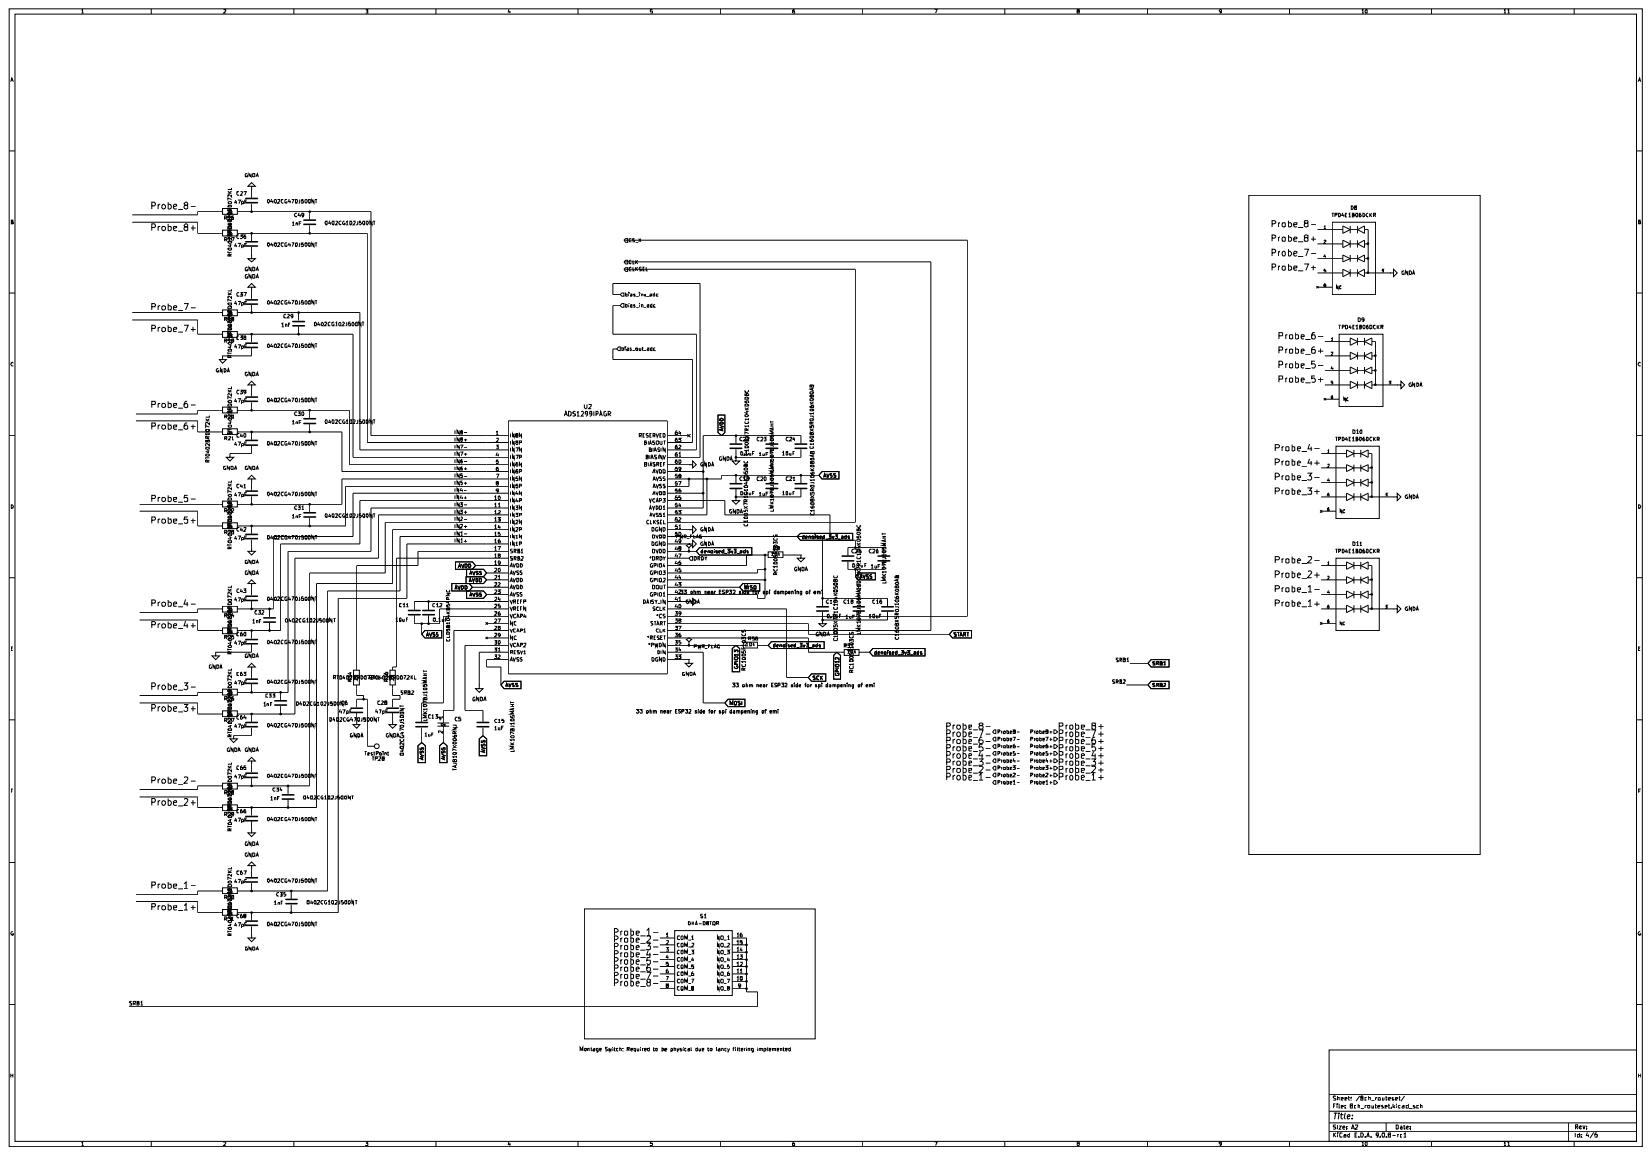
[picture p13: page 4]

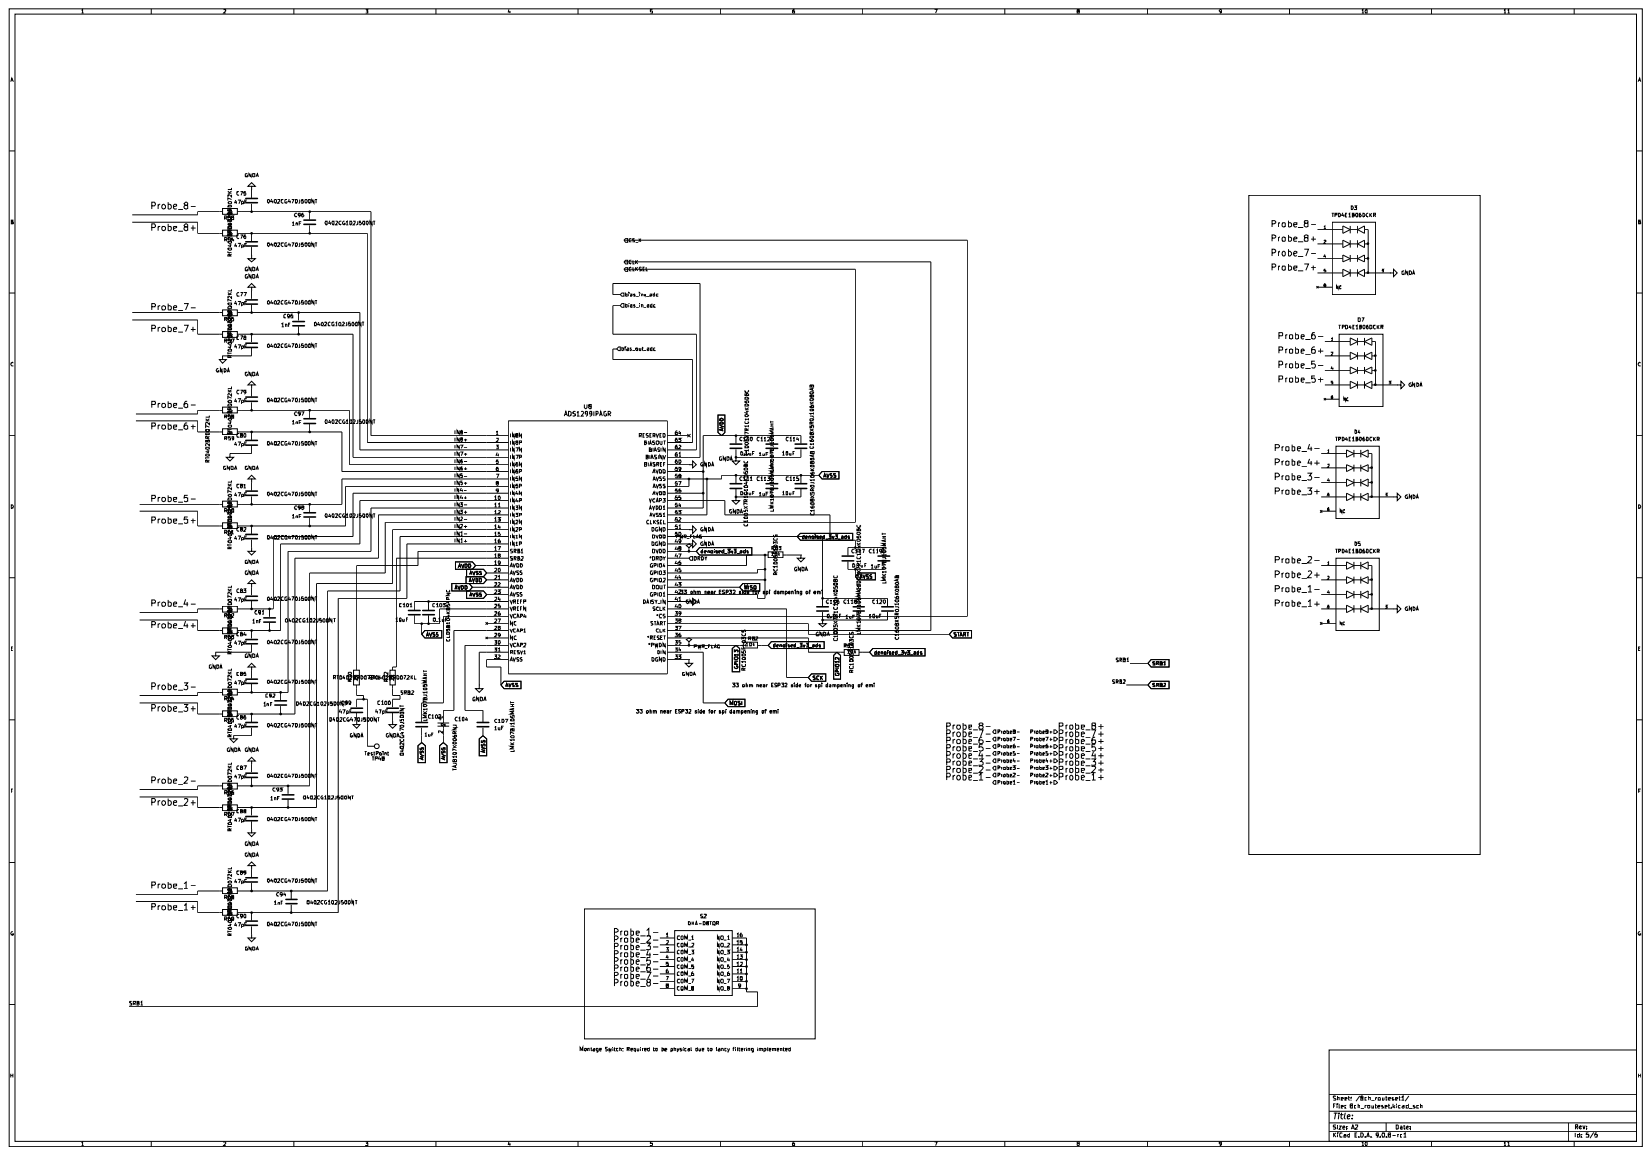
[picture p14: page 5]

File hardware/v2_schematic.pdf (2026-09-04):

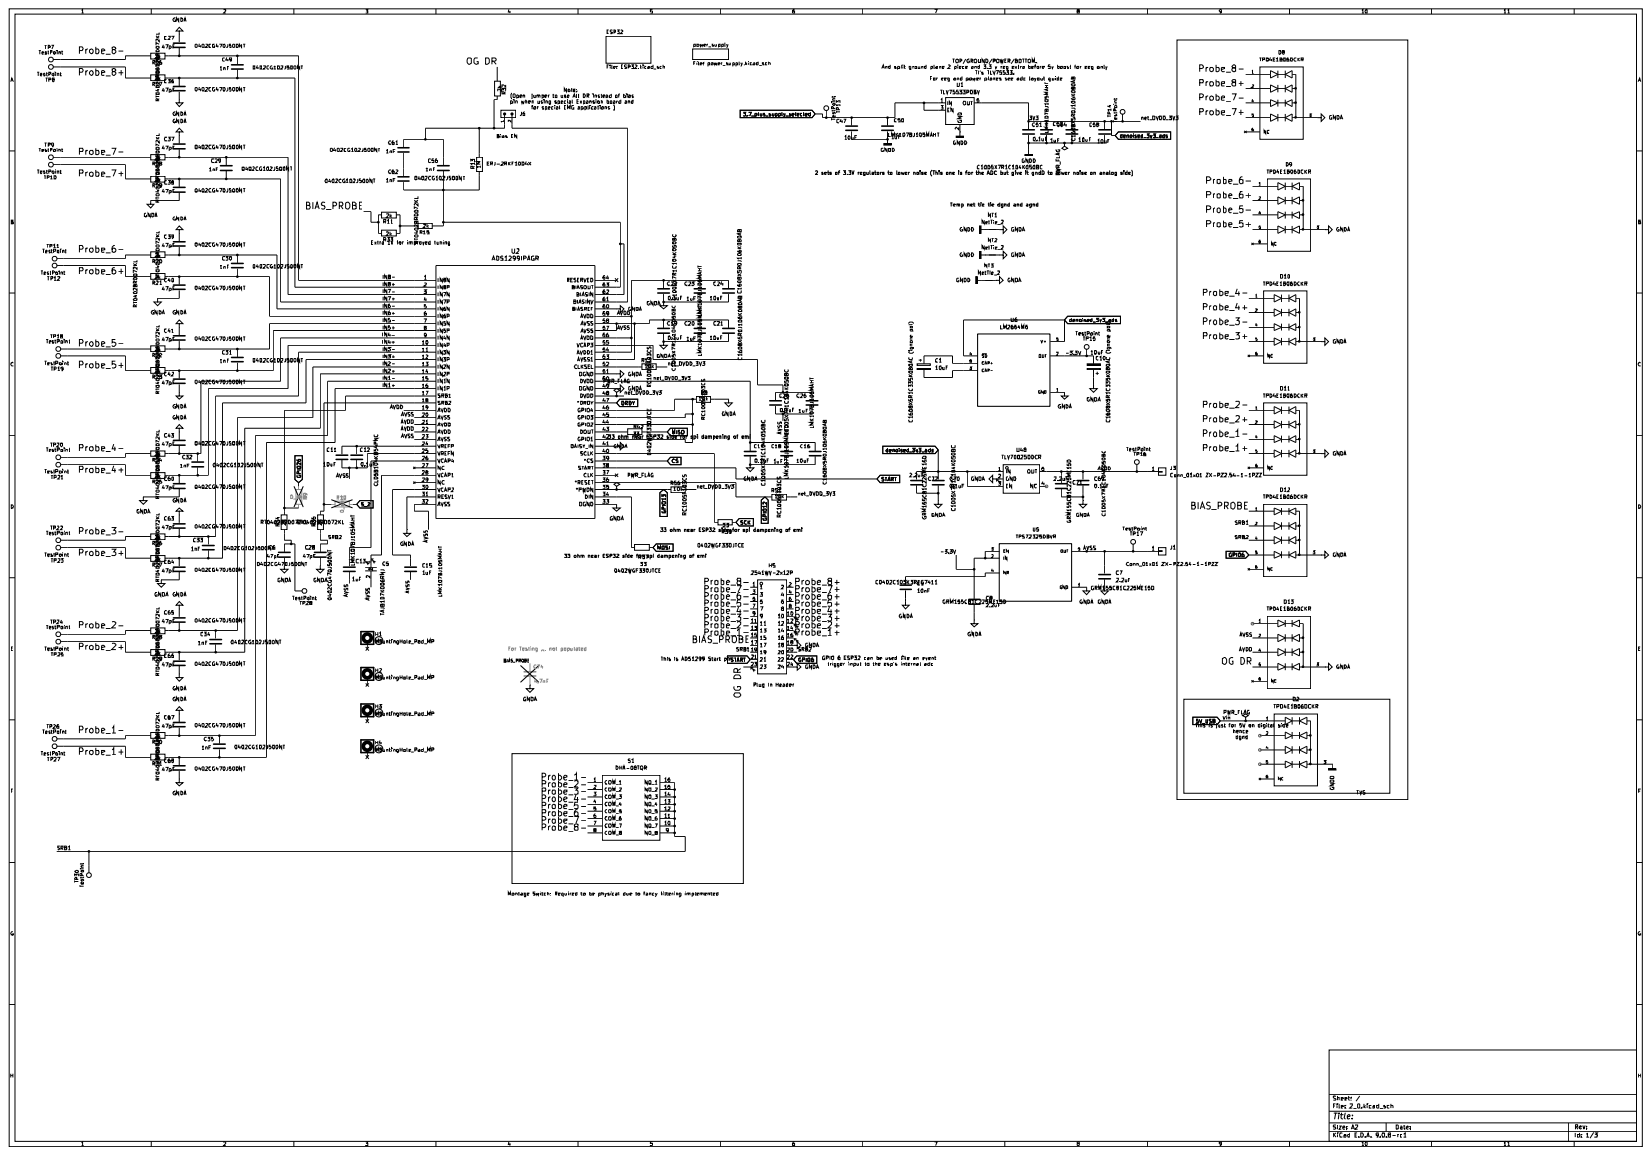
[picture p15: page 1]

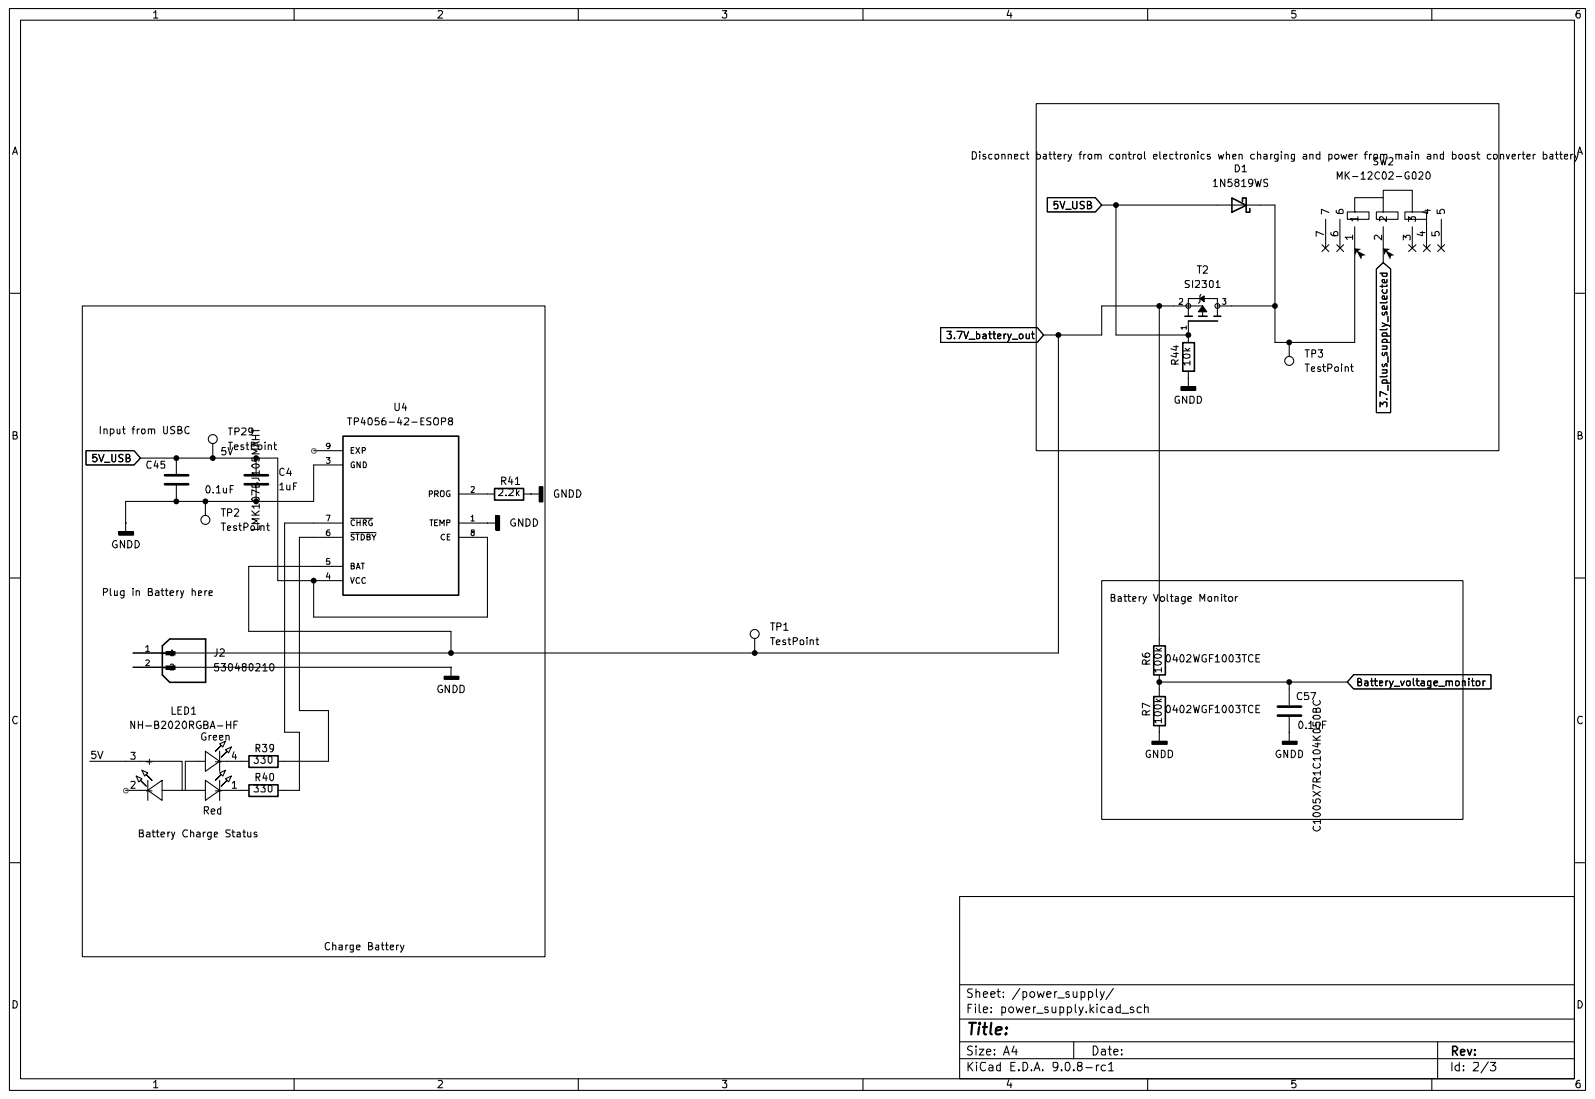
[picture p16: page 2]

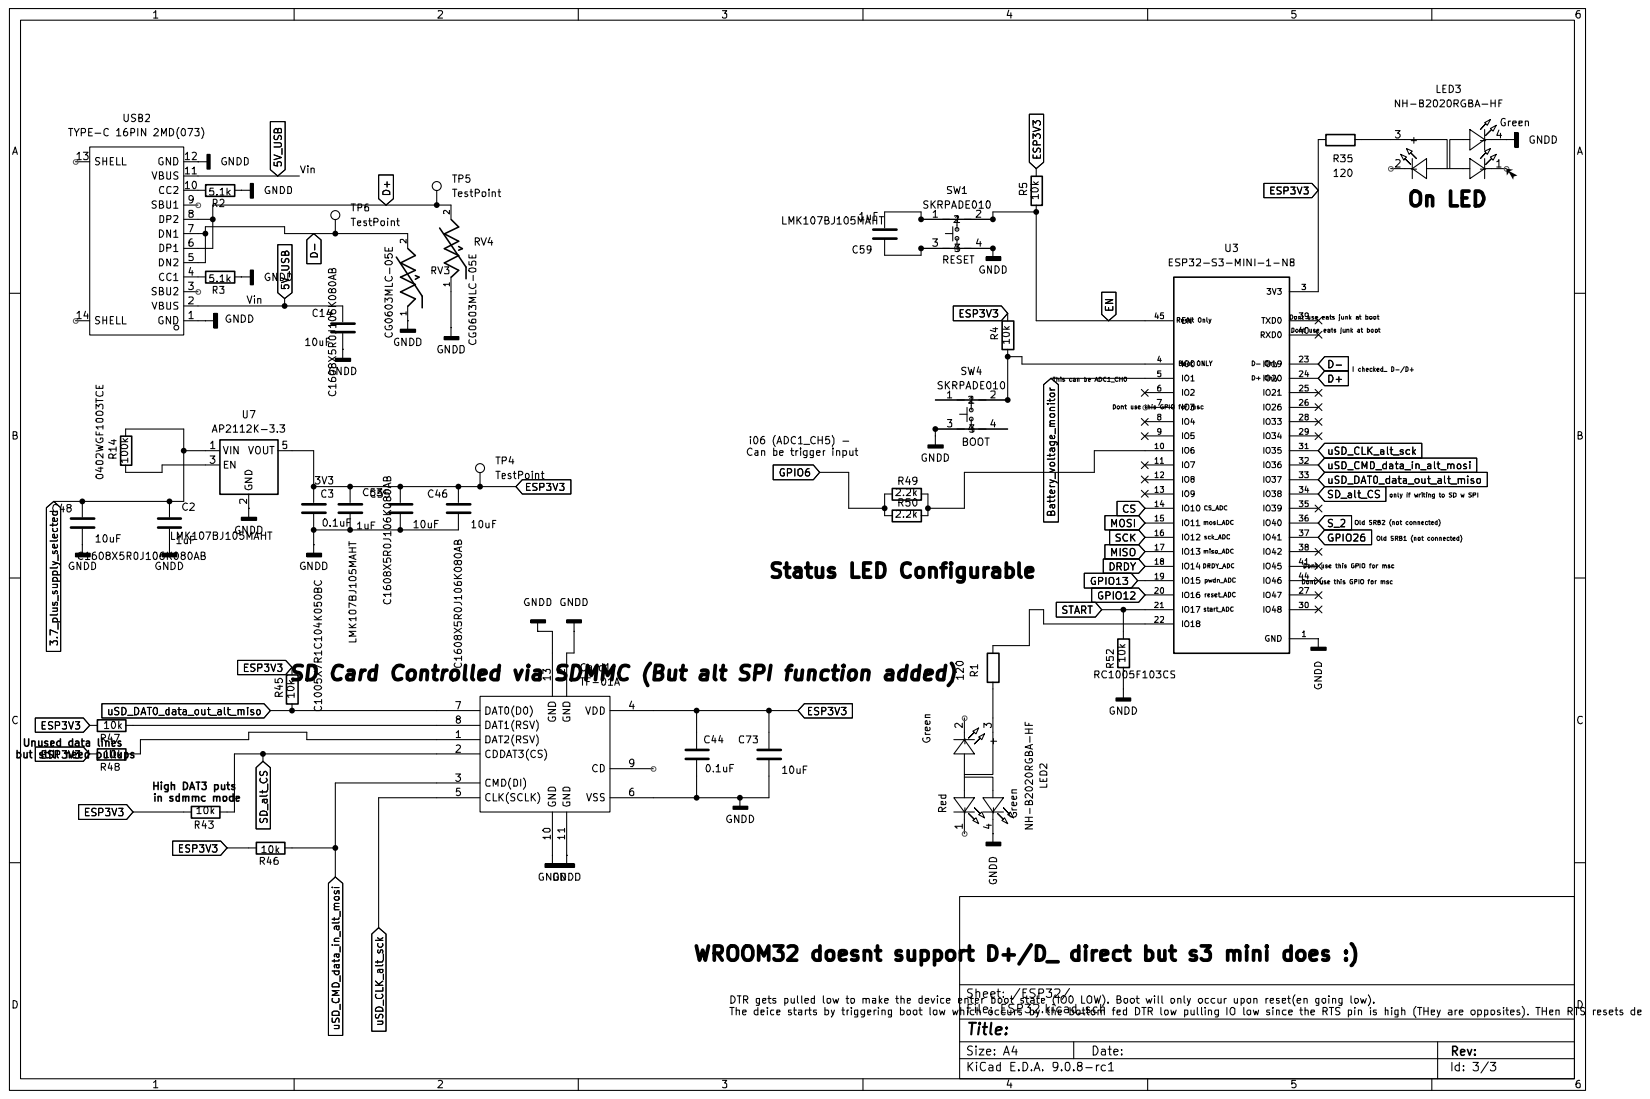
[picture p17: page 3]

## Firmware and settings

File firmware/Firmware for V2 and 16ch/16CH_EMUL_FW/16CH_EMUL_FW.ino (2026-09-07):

#include <Arduino.h>
#include <SPI.h>
#include "esp_log.h"

// --- USB identity -----------------------------------------------------------
// The OpenBCI GUI only lists a serial port under EMUL if the USB product
// string starts with "FT231X USB UART" or "VCP":
//
//   the GUI's serial-port filter:
//     String[] names = {"FT231X USB UART", "VCP"};
//     if (port.toString().startsWith(name)) { ...add port... }
//
// The ESP32-S3's built-in USB-Serial-JTAG reports "USB JTAG/serial debug unit"
// and that string is fixed in silicon, so this sketch runs the USB-OTG
// (TinyUSB) stack instead and names itself with a "VCP" prefix.  VID/PID stay
// Espressif's - nothing here pretends to be FTDI hardware.
//
//   *** REQUIRED Arduino IDE settings for THIS sketch ***
//     Tools -> Board            : ESP32-S3 Dev Module
//     Tools -> USB Mode         : USB-OTG (TinyUSB)      <-- differs from the
//     Tools -> USB CDC On Boot  : Disabled               <-- other sketches
//     Tools -> Flash Size       : 4MB (32Mb)
//
// CDC On Boot MUST be Disabled: with it enabled the core calls USB.begin()
// from main() before setup() runs (USB.h defines ARDUINO_USB_ON_BOOT from it),
// tinyusb_init() latches the descriptor, and USB.productName() then silently
// does nothing - the port would show up as "ESP32S3_DEV" and the GUI would
// filter it out.  So this sketch owns its own CDC instance instead.
#if ARDUINO_USB_MODE != 0
#error "16CH_EMUL_FW: set Tools > USB Mode = 'USB-OTG (TinyUSB)'. The OpenBCI GUI cannot see this board in Hardware CDC and JTAG mode."
#endif
#if ARDUINO_USB_CDC_ON_BOOT != 0
#error "16CH_EMUL_FW: set Tools > USB CDC On Boot = 'Disabled'. With CDC on boot the USB product string is latched before setup() and the OpenBCI GUI will not list this port."
#endif

#include "USB.h"
#include "USBCDC.h"

#define OBCI_USB_PRODUCT      "VCP Cerelog ESP-EEG 16CH"
#define OBCI_USB_MANUFACTURER "Cerelog"

// Our own CDC endpoint.  Constructed before setup(), which registers the CDC
// interface with TinyUSB; USB.begin() in setup() then starts the stack.
USBCDC CDCSerial;

// ============================================================================
//  16 CHANNEL FIRMWARE - NATIVE OpenBCI GUI STREAMING (EMUL protocol)
//
//  Same 2x ADS1299 hardware as 16CH_FW.ino, but the serial layer speaks the
//  EMUL 16-channel protocol, which the stock OpenBCI GUI reads natively.
//  See the project notes for which Control Panel entry to select.
//
//  ADC1 ("master")   : CS on IO10.  CLK_SEL pin = 1 (internal oscillator),
//                      CONFIG1.CLK_EN = 1 so it drives its clock out to ADC2.
//                      Bias amplifier is the ONLY bias amp running, driven
//                      from CH1P / CH1N only.
//  ADC2 ("follower") : CS on IO48.  Clocked from ADC1's CLK output, so
//                      CONFIG1.CLK_EN = 0.  CONFIG3.PD_BIAS = 0 and
//                      BIAS_SENSP/BIAS_SENSN = 0.
//
//  Both parts share DRDY (IO14), PWDN (IO15), RESET (IO16) and START (IO17).
//
//  --- WIRE FORMAT (33 bytes, EMUL) -----------------------------------------
//    byte  0      0xA0                         start byte
//    byte  1      sample counter, 0..255       EVEN = daisy, ODD = emul
//    bytes 2-25   8 channels x 24-bit BE       (ch9..16 on even, ch1..8 on odd)
//    bytes 26-31  6 aux bytes                  zero (no accelerometer fitted)
//    byte  32     0xC0                         standard stop byte
//
//  The BrainFlow reader the GUI uses joins an even packet and the following
//  odd packet into one 16-channel sample, so packets are emitted in pairs:
//  channels 9-16 first, then channels 1-8.  The pair rate is 125 Hz, which is
//  the rate BrainFlow assumes for this 16-channel serial board - it is not
//  negotiable on the wire.  The ADS1299 minimum rate is 250 SPS, so two
//  consecutive 250 Hz conversions are averaged down to one 125 Hz sample.
// ============================================================================


// #define DEBUG_ENABLED // Uncomment when debugging ONLY - will corrupt data otherwise


#ifdef DEBUG_ENABLED
#define DEBUG_PRINT(...) CDCSerial.print(__VA_ARGS__) // accepts variable arguments
#define DEBUG_PRINTLN(...) CDCSerial.println(__VA_ARGS__)
#else
#define DEBUG_PRINT(...)
#define DEBUG_PRINTLN(...)
#endif




// --- ADS1299 geometry ---
const uint8_t ADS1299_NUM_DEVICES = 2;
const uint8_t ADS1299_NUM_STATUS_BYTES = 3;
const uint8_t ADS1299_NUM_CHANNELS = 8;   // per device
const uint8_t ADS1299_BYTES_PER_CHANNEL = 3;
const uint8_t ADS1299_TOTAL_DATA_BYTES = ADS1299_NUM_STATUS_BYTES + (ADS1299_NUM_CHANNELS * ADS1299_BYTES_PER_CHANNEL);
const uint8_t ADS1299_ALL_DATA_BYTES = ADS1299_TOTAL_DATA_BYTES * ADS1299_NUM_DEVICES;
const uint8_t TOTAL_NUM_CHANNELS = ADS1299_NUM_CHANNELS * ADS1299_NUM_DEVICES; // 16


// --- EMUL packet constants ---
static const uint8_t OBCI_PACKET_SIZE = 33;
static const uint8_t OBCI_START_BYTE = 0xA0;
static const uint8_t OBCI_STOP_BYTE_STANDARD = 0xC0;
// --- GUI hardware-settings lock -------------------------------------------
// The OpenBCI GUI's Hardware Settings panel can push per-channel commands
// ('x C p g i b s r X') and the channel on/off characters.  With this set to 0
// those commands are still ACKed so the GUI stays happy, but NOT ONE ADS1299
// register is written: the board keeps exactly the configuration that
// ADS1299_SETUP() established, including the bias policy (ADC1 only, fed from
// CH1P/CH1N alone, ADC2's bias amp powered down) and the montage switch's
// SRB1 setting in MISC1.
// Set to 1 to let the GUI drive power-down / gain / input type / SRB2.
#define OBCI_ALLOW_GUI_HARDWARE_SETTINGS 0

// How many 250 SPS conversions are averaged into one transmitted sample.
// 2 -> 125 Hz, which is what BrainFlow expects from EMUL_DAISY_BOARD.
static const uint8_t OBCI_DOWNSAMPLE = 2;




// --- Pin Mapping ---
static const uint8_t pin_BATT_MON = 1;     // ADC1_CH0, battery voltage monitor
static const uint8_t pin_TRIGGER_IN = 6;   // ADC1_CH5, reserved for future use
static const uint8_t pin_CS1_NUM = 10;     // Chip select, ADC1 (master / clock source / bias amp)
static const uint8_t pin_CS2_NUM = 48;     // Chip select, ADC2 (follower / external clock)
static const uint8_t pin_MOSI_NUM = 11;
static const uint8_t pin_SCK_NUM = 12;
static const uint8_t pin_MISO_NUM = 13;
static const uint8_t pin_DRDY_NUM = 14;    // shared by both devices
static const uint8_t pin_PWDN_NUM = 15;    // shared by both devices
static const uint8_t pin_RST_NUM = 16;     // shared by both devices
static const uint8_t pin_START_NUM = 17;   // shared by both devices - hardware sync
static const uint8_t pin_LED_DEBUG = 18;

// --- SD Card Pin Mapping ---
static const uint8_t pin_SD_CLK = 35;   // SD_CLK / SCLK
static const uint8_t pin_SD_CMD = 36;   // SD_CMD / MOSI
static const uint8_t pin_SD_DAT0 = 37;  // SD_DAT0 / MISO
static const uint8_t pin_SD_CS = 38;




// --- SPI instance ---
SPIClass *vspi = NULL;

static const int SPI_FREQ = 4000000;




// --- Register Setup ---
typedef struct Deez { int add; int reg_val; } regVal_pair;
const int size_reg_ls = 24;

// ---------------- ADC1 (master) ----------------
// 0x01 CONFIG1 = 0b1011_0110 : CLK_EN = 1 -> internal oscillator routed OUT of
//                              the CLK pin to feed ADC2.  DR = 110 (250 SPS).
// 0x03 CONFIG3 = 0b1110_1100 : PD_REFBUF = 1, BIASREF_INT = 1, PD_BIAS = 1
//                              -> the ONLY bias amplifier that is powered.
// 0x0D/0x0E BIAS_SENSP/N = 0b0000_0001 -> only CH1P and CH1N feed the bias loop.
static const regVal_pair ADS1299_REGISTER_LS[size_reg_ls] = {
  {0x01, 0b10110110}, {0x02, 0b11010000}, {0x03, 0b11101100}, {0x04, 0}, {-2, -2},
  {0x05, 0b01100000}, {0x06, 0b01100000}, {0x07, 0b01100000}, {0x08, 0b01100000},
  {0x09, 0b01100000}, {0x0A, 0b01100000}, {0x0B, 0b01100000}, {0x0C, 0b01100000},
  {0x0D, 0b00000001}, {0x0E, 0b00000001}, {0x0F, 0}, {0x10, 0}, {0x11, 0}, {-2, -2},
  {0x15, 0b00000000}, {0x16, 0}, {0x17, 0} // DO NOT EDIT 0x15 (MISC1) - use the montage switch on the PCB to select between SRB1 and differential mode. Modifying this value will stop the device from working.
};

// ---------------- ADC2 (follower) ----------------
// 0x01 CONFIG1 = 0b1001_0110 : CLK_EN = 0.  ADC2's CLK pin is an INPUT fed by
//                              ADC1, so it must not drive the shared clock net.
// 0x03 CONFIG3 = 0b1110_1000 : PD_BIAS = 0 -> ADC2's bias amplifier POWERED DOWN.
// 0x0D/0x0E BIAS_SENSP/N = 0  -> no ADC2 channel enters any bias loop.
static const regVal_pair ADS1299_REGISTER_LS_2[size_reg_ls] = {
  {0x01, 0b10010110}, {0x02, 0b11010000}, {0x03, 0b11101000}, {0x04, 0}, {-2, -2},
  {0x05, 0b01100000}, {0x06, 0b01100000}, {0x07, 0b01100000}, {0x08, 0b01100000},
  {0x09, 0b01100000}, {0x0A, 0b01100000}, {0x0B, 0b01100000}, {0x0C, 0b01100000},
  {0x0D, 0b00000000}, {0x0E, 0b00000000}, {0x0F, 0}, {0x10, 0}, {0x11, 0}, {-2, -2},
  {0x15, 0b00000000}, {0x16, 0}, {0x17, 0} // DO NOT EDIT 0x15 (MISC1) - montage switch on the PCB controls SRB1 vs differential mode.
};




// --- ADS1299 State Management ---
int _ADS1299_MODE[ADS1299_NUM_DEVICES] = {-2, -2};
int ADS1299_MODE_SDATAC = 1;
int ADS1299_MODE_RDATAC = 2;
int _ADS1299_PREV_CMD = -1;
int _CMD_ADC_WREG = 3;
int _CMD_ADC_RREG = 4;
int _CMD_ADC_SDATAC = 17;
int _CMD_ADC_RDATAC = 16;
int _CMD_ADC_START = 8;

static inline uint8_t cs_to_index(uint8_t cs) { return (cs == pin_CS1_NUM) ? 0 : 1; }

// Live copy of each device's CHnSET registers so the OpenBCI 'x' / channel
// on-off commands can read-modify-write without an extra SPI read.
uint8_t chset_shadow[ADS1299_NUM_DEVICES][ADS1299_NUM_CHANNELS] = {
  {0x60,0x60,0x60,0x60,0x60,0x60,0x60,0x60},
  {0x60,0x60,0x60,0x60,0x60,0x60,0x60,0x60}
};




// --- Interrupt Flag ---
volatile bool dataReady = false;

// --- Streaming state (OpenBCI boards boot idle and stream only after 'b') ---
volatile bool streaming = false;
uint8_t sampleCounter = 0;

// --- Downsampling accumulators (250 SPS in, 125 Hz out) ---
int32_t acc_ch1_8[ADS1299_NUM_CHANNELS];  // ADC1 -> OpenBCI channels 1..8
int32_t acc_ch9_16[ADS1299_NUM_CHANNELS];  // ADC2 -> OpenBCI channels 9..16
uint8_t acc_count = 0;

unsigned long _millis_reference = 0;




// --- Function Prototypes ---
void ADS1299_WREG(uint8_t cs, uint8_t regAdd, uint8_t *values, uint8_t numRegs);
void ADS1299_RREG(uint8_t cs, uint8_t regAdd, uint8_t *buffer, uint8_t numRegs);
void ADS1299_SETUP(void);
static void ADS1299_WRITE_TABLE(uint8_t cs, const regVal_pair *table);
void ADS1299_SDATAC(uint8_t cs);
void ADS1299_RDATAC(uint8_t cs);
void ADS1299_START(uint8_t cs);
byte SPI_SendByte(uint8_t cs, byte data_byte, bool cont);
void read_ADS1299_data(uint8_t cs, byte *buffer);
void read_ADS1299_data_all(byte *buffer);
void IRAM_ATTR onDRDYFalling(void);
void obci_process_serial(void);
void obci_send_packet(uint8_t counter, const int32_t *ch8);

// ============================================================
// === SD CARD LOGGING SECTION - START ========================
// ============================================================
#include "SD_MMC.h"
#include "SD.h"
#include "FS.h"

typedef struct {
    uint32_t timestamp_ms;
    int32_t  ch[16];      // raw 250 SPS conversions, NOT the averaged stream
    uint32_t status1;
    uint32_t status2;
} sd_sample_t;

typedef struct {
    bool sd_available;
    bool logging_active;
    File file;
    int file_number;
    uint32_t samples_written;
} sd_state_t;

sd_state_t sd_state = {false, false, File(), 0, 0};
fs::FS *sd_fs = NULL; // Points to whichever filesystem initialized successfully
QueueHandle_t sd_queue = NULL;
volatile uint32_t sd_dropped_count = 0;

bool sd_init() {
    // No GPIO-level card detect — both inserted and absent cards read HIGH on
    // DAT0 with a pull-up, making the check unreliable.  Instead just attempt
    // SD_MMC.begin() directly.  The ~3 s timeout when no card is present is
    // acceptable because sd_init() runs on core 0 via sd_setup_task and never
    // blocks the data-streaming loop on core 1.
    SD_MMC.setPins(pin_SD_CLK, pin_SD_CMD, pin_SD_DAT0);
    if (SD_MMC.begin("/sdcard", true)) {
        DEBUG_PRINTLN("SD: SDMMC 1-bit mode OK");
        sd_fs = &SD_MMC;
        return true;
    }
    DEBUG_PRINTLN("SD: SDMMC init failed, no card?");
    return false;
}

void sd_get_next_filename(char *buf, size_t len) {
    for (int i = 1; i <= 999; i++) {
        snprintf(buf, len, "/REC_%03d.csv", i);
        if (!sd_fs->exists(buf)) {
            sd_state.file_number = i;
            return;
        }
    }
    // All 999 used, overwrite last
    snprintf(buf, len, "/REC_999.csv");
    sd_state.file_number = 999;
}

bool sd_open_new_file() {
    char filename[20];
    sd_get_next_filename(filename, sizeof(filename));
    sd_state.file = sd_fs->open(filename, FILE_WRITE);
    if (!sd_state.file) {
        DEBUG_PRINT("SD: Failed to open "); DEBUG_PRINTLN(filename);
        sd_state.logging_active = false;
        return false;
    }
    // ch1..ch8 come from ADC1, ch9..ch16 from ADC2.  Each device has its own
    // 24-bit status word, so both are logged.  Rows are written at the full
    // 250 SPS conversion rate - the 125 Hz averaging exists only on the wire.
    sd_state.file.println("timestamp_ms,status1,ch1,ch2,ch3,ch4,ch5,ch6,ch7,ch8,status2,ch9,ch10,ch11,ch12,ch13,ch14,ch15,ch16");
    sd_state.logging_active = true;
    sd_state.samples_written = 0;
    DEBUG_PRINT("SD: Recording to "); DEBUG_PRINTLN(filename);
    return true;
}

void sd_log_task(void *param) {
    sd_sample_t sample;
    unsigned long last_flush = millis();
    uint32_t last_logged_drops = 0;
    char line[320];

    while (true) {
        if (xQueueReceive(sd_queue, &sample, pdMS_TO_TICKS(100)) == pdTRUE) {
            if (!sd_state.logging_active) continue;

            // Log any dropped samples as a comment
            uint32_t drops = sd_dropped_count;
            if (drops > last_logged_drops) {
                uint32_t new_drops = drops - last_logged_drops;
                last_logged_drops = drops;
                char drop_line[48];
                snprintf(drop_line, sizeof(drop_line), "# DROPPED %lu samples\n", (unsigned long)new_drops);
                sd_state.file.print(drop_line);
            }

            snprintf(line, sizeof(line),
                     "%lu,0x%06lX,%ld,%ld,%ld,%ld,%ld,%ld,%ld,%ld,0x%06lX,%ld,%ld,%ld,%ld,%ld,%ld,%ld,%ld\n",
                     (unsigned long)sample.timestamp_ms,
                     (unsigned long)sample.status1,
                     (long)sample.ch[0], (long)sample.ch[1], (long)sample.ch[2], (long)sample.ch[3],
                     (long)sample.ch[4], (long)sample.ch[5], (long)sample.ch[6], (long)sample.ch[7],
                     (unsigned long)sample.status2,
                     (long)sample.ch[8],  (long)sample.ch[9],  (long)sample.ch[10], (long)sample.ch[11],
                     (long)sample.ch[12], (long)sample.ch[13], (long)sample.ch[14], (long)sample.ch[15]);

            size_t written = sd_state.file.print(line);
            if (written == 0) {
                // Write failed — SD removed or full
                sd_state.logging_active = false;
                sd_state.file.close();
                DEBUG_PRINTLN("SD: Write failed, logging stopped");
                continue;
            }
            sd_state.samples_written++;
        }

        // Flush every 1 second
        if (sd_state.logging_active && (millis() - last_flush >= 1000)) {
            sd_state.file.flush();
            last_flush = millis();
        }
    }
}

// --- SD background init task: runs entirely on core 0 so it never blocks loop() ---
void sd_setup_task(void *param) {
    if (sd_init()) {
        sd_state.sd_available = true;
        sd_queue = xQueueCreate(256, sizeof(sd_sample_t));
        if (sd_queue != NULL) {
            sd_open_new_file();
            if (sd_state.logging_active) {
                xTaskCreatePinnedToCore(sd_log_task, "SD_Log", 8192, NULL, 1, NULL, 0);
            } else {
                vQueueDelete(sd_queue);
                sd_queue = NULL;
            }
        }
    }
    vTaskDelete(NULL); // self-delete when done
}
// ============================================================
// === SD CARD LOGGING SECTION - END ==========================
// ============================================================




void IRAM_ATTR onDRDYFalling(void) { dataReady = true; }




// --- SPI primitives.  Every call takes the chip select of the device it is
//     talking to; only one CS is ever low at a time so the two ADS1299s never
//     both drive the shared MISO line. ---
byte SPI_SendByte(uint8_t cs, byte data_byte, bool cont) {
  if (!cont) { digitalWrite(cs, LOW); delayMicroseconds(1); }
  byte received = vspi->transfer(data_byte);
  if (!cont) { delayMicroseconds(1); digitalWrite(cs, HIGH); }
  return received;
}


void ADS1299_WREG(uint8_t cs, uint8_t regAdd, uint8_t *values, uint8_t numRegs) {
  if (_ADS1299_MODE[cs_to_index(cs)] != ADS1299_MODE_SDATAC) ADS1299_SDATAC(cs);
  digitalWrite(cs, LOW);
  delayMicroseconds(1);
  SPI_SendByte(cs, 0b01000000 | regAdd, true);
  SPI_SendByte(cs, numRegs - 1, true);
  for (uint8_t i = 0; i < numRegs; i++) SPI_SendByte(cs, values[i], true);
  delayMicroseconds(1);
  digitalWrite(cs, HIGH);
  _ADS1299_PREV_CMD = _CMD_ADC_WREG;
}


void ADS1299_RREG(uint8_t cs, uint8_t regAdd, uint8_t *buffer, uint8_t numRegs) {
  if (_ADS1299_MODE[cs_to_index(cs)] != ADS1299_MODE_SDATAC) ADS1299_SDATAC(cs);
  digitalWrite(cs, LOW);
  delayMicroseconds(1);
  SPI_SendByte(cs, 0b00100000 | regAdd, true);
  SPI_SendByte(cs, numRegs - 1, true);
  for (uint8_t i = 0; i < numRegs; i++) buffer[i] = SPI_SendByte(cs, 0x00, true);
  delayMicroseconds(1);
  digitalWrite(cs, HIGH);
  _ADS1299_PREV_CMD = _CMD_ADC_RREG;
}


void ADS1299_SDATAC(uint8_t cs) {
  digitalWrite(cs, LOW);
  delayMicroseconds(1);
  SPI_SendByte(cs, _CMD_ADC_SDATAC, true);
  delayMicroseconds(1);
  digitalWrite(cs, HIGH);
  _ADS1299_MODE[cs_to_index(cs)] = ADS1299_MODE_SDATAC;
  _ADS1299_PREV_CMD = _CMD_ADC_SDATAC;
}


void ADS1299_RDATAC(uint8_t cs) {
  digitalWrite(cs, LOW);
  delayMicroseconds(1);
  SPI_SendByte(cs, _CMD_ADC_RDATAC, true);
  delayMicroseconds(1);
  digitalWrite(cs, HIGH);
  _ADS1299_MODE[cs_to_index(cs)] = ADS1299_MODE_RDATAC;
  _ADS1299_PREV_CMD = _CMD_ADC_RDATAC;
}


// Kept for completeness.  Conversions are started with the shared hardware
// START pin (IO17) so both devices begin on the same edge of the same clock.
void ADS1299_START(uint8_t cs) {
  digitalWrite(cs, LOW);
  delayMicroseconds(1);
  SPI_SendByte(cs, _CMD_ADC_START, true);
  delayMicroseconds(1);
  digitalWrite(cs, HIGH);
  _ADS1299_PREV_CMD = _CMD_ADC_START;
}


static void ADS1299_WRITE_TABLE(uint8_t cs, const regVal_pair *table) {
  uint8_t value[1];
  uint8_t i = 0;
  while (i < size_reg_ls) {
      const regVal_pair temp = table[i];
      if (temp.add == -2) { i++; continue; }
      value[0] = (uint8_t)temp.reg_val;
      ADS1299_WREG(cs, temp.add, value, 1);
      if (temp.add >= 0x05 && temp.add <= 0x0C) {
          chset_shadow[cs_to_index(cs)][temp.add - 0x05] = (uint8_t)temp.reg_val;
      }
      delayMicroseconds(10);
      i++;
  }
}
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
void loop() {
  obci_process_serial();

  if (!dataReady) return;
  dataReady = false;

  byte raw_data[ADS1299_ALL_DATA_BYTES];
  read_ADS1299_data_all(raw_data);

  // --- SD card: log every conversion at the full 250 SPS rate. ---------------
  // This runs before the streaming gate on purpose: the card records whenever
  // the board is powered, exactly like 16CH_FW.ino, and is unaffected by the
  // 2-sample averaging that the 125 Hz wire format forces on the GUI stream.
  if (sd_queue != NULL) {
      sd_sample_t sample;
      sample.timestamp_ms = millis() - _millis_reference;
      sample.status1 = ((uint32_t)raw_data[0] << 16) | ((uint32_t)raw_data[1] << 8) | raw_data[2];
      sample.status2 = ((uint32_t)raw_data[27] << 16) | ((uint32_t)raw_data[28] << 8) | raw_data[29];
      for (uint8_t i = 0; i < ADS1299_NUM_CHANNELS; i++) {
          sample.ch[i]     = conv24(&raw_data[3 + 3 * i]);
          sample.ch[i + 8] = conv24(&raw_data[ADS1299_TOTAL_DATA_BYTES + 3 + 3 * i]);
      }
      if (xQueueSend(sd_queue, &sample, 0) != pdTRUE) {
          sd_dropped_count++;
      }
  }

  if (!streaming) return;

  // Accumulate 250 SPS conversions; emit once every OBCI_DOWNSAMPLE of them.
  if (acc_count == 0) {
      for (uint8_t i = 0; i < ADS1299_NUM_CHANNELS; i++) {
          acc_ch1_8[i] = conv24(&raw_data[3 + 3 * i]);
          acc_ch9_16[i] = conv24(&raw_data[ADS1299_TOTAL_DATA_BYTES + 3 + 3 * i]);
      }
  } else {
      for (uint8_t i = 0; i < ADS1299_NUM_CHANNELS; i++) {
          acc_ch1_8[i] += conv24(&raw_data[3 + 3 * i]);
          acc_ch9_16[i] += conv24(&raw_data[ADS1299_TOTAL_DATA_BYTES + 3 + 3 * i]);
      }
  }
  acc_count++;

  if (acc_count < OBCI_DOWNSAMPLE) return;
  acc_count = 0;

  int32_t ch1_8[ADS1299_NUM_CHANNELS];
  int32_t ch9_16[ADS1299_NUM_CHANNELS];
  for (uint8_t i = 0; i < ADS1299_NUM_CHANNELS; i++) {
      ch1_8[i] = acc_ch1_8[i] / (int32_t)OBCI_DOWNSAMPLE;
      ch9_16[i] = acc_ch9_16[i] / (int32_t)OBCI_DOWNSAMPLE;
  }

  // Channels 9-16 go out on the EVEN counter, 1-8 on the ODD counter.
  // The host joins the pair into one 16-channel sample and commits on the odd.
  obci_send_packet(sampleCounter++, ch9_16);
  obci_send_packet(sampleCounter++, ch1_8);

}

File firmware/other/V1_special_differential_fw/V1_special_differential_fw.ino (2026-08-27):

#include <Arduino.h>
#include <SPI.h>
















// #define DEBUG_ENABLED // Uncomment when debugging ONLY - will corrupt data otherwise
















#ifdef DEBUG_ENABLED
#define DEBUG_PRINT(...) Serial.print(__VA_ARGS__) // accepts variable arguments
#define DEBUG_PRINTLN(...) Serial.println(__VA_ARGS__)
#else
#define DEBUG_PRINT(...)
#define DEBUG_PRINTLN(...)
#endif
















// --- Packet/Protocol Global Variables ---
const uint8_t ADS1299_NUM_STATUS_BYTES = 3;
const uint8_t ADS1299_NUM_CHANNELS = 8;
const uint8_t ADS1299_BYTES_PER_CHANNEL = 3;
const uint8_t ADS1299_TOTAL_DATA_BYTES = ADS1299_NUM_STATUS_BYTES + (ADS1299_NUM_CHANNELS * ADS1299_BYTES_PER_CHANNEL);
const uint8_t PACKET_TIMESTAMP_BYTES = 4;
const uint8_t PACKET_START_MARKER_BYTES = 2;
const uint8_t PACKET_END_MARKER_BYTES = 2;
const uint8_t PACKET_LENGTH_FIELD_BYTES = 1;
const uint8_t PACKET_CHECKSUM_BYTES = 1;
const uint8_t PACKET_MSG_LENGTH = PACKET_TIMESTAMP_BYTES + ADS1299_TOTAL_DATA_BYTES;
const uint8_t PACKET_TOTAL_SIZE = PACKET_START_MARKER_BYTES + PACKET_LENGTH_FIELD_BYTES + PACKET_MSG_LENGTH + PACKET_CHECKSUM_BYTES + PACKET_END_MARKER_BYTES;
const uint8_t PACKET_IDX_START_MARKER = 0;
const uint8_t PACKET_IDX_LENGTH = PACKET_IDX_START_MARKER + PACKET_START_MARKER_BYTES;
const uint8_t PACKET_IDX_TIMESTAMP = PACKET_IDX_LENGTH + PACKET_LENGTH_FIELD_BYTES;
const uint8_t PACKET_IDX_ADS1299_DATA = PACKET_IDX_TIMESTAMP + PACKET_TIMESTAMP_BYTES;
const uint8_t PACKET_IDX_CHECKSUM = PACKET_IDX_ADS1299_DATA + ADS1299_TOTAL_DATA_BYTES;
const uint8_t PACKET_IDX_END_MARKER = PACKET_IDX_CHECKSUM + PACKET_CHECKSUM_BYTES;
















// --- Pin Mapping ---
static const uint8_t pin_MOSI_NUM = 23;
static const uint8_t pin_CS_NUM = 5;
static const uint8_t pin_MISO_NUM = 19;
static const uint8_t pin_SCK_NUM = 18;
static const uint8_t pin_PWDN_NUM = 13;
static const uint8_t pin_RST_NUM = 12;
static const uint8_t pin_START_NUM = 14;
static const uint8_t pin_DRDY_NUM = 27;
static const uint8_t pin_LED_DEBUG = 17;
















// --- SPI instance ---
SPIClass *vspi = NULL;
















// Query Timing Setup
unsigned long _last_query_time = 0;
static const int SPI_FREQ = 4000000;
static const int SAMPLE_FREQ = 250;
static const float SAMPLE_PRD_us = (1.0 / SAMPLE_FREQ) * 1000000;
















// --- ADS1299 State Management ---
int _ADS1299_MODE = -2;
int ADS1299_MODE_SDATAC = 1;
int ADS1299_MODE_RDATAC = 2;
int _ADS1299_PREV_CMD = -1;
int _CMD_ADC_WREG = 3;
int _CMD_ADC_RREG = 4;
int _CMD_ADC_SDATAC = 17;
int _CMD_ADC_RDATAC = 16;
int _CMD_ADC_START = 8;
















// --- Interrupt Flag & Timestamp ---
volatile bool dataReady = false;
unsigned long _unix_timestamp_reference = 0;
unsigned long _millis_reference = 0;
bool _timestamp_initialized = false;
















// --- Function Prototypes ---
void ADS1299_WREG(uint8_t regAdd, uint8_t *values, uint8_t numRegs);
void ADS1299_RREG(uint8_t regAdd, uint8_t *buffer, uint8_t numRegs);
void ADS1299_SETUP(void);
void ADS1299_SDATAC(void);
void ADS1299_RDATAC(void);
void ADS1299_START(void);
byte SPI_SendByte(byte data_byte, bool cont);
void read_ADS1299_data(byte *buffer);
void IRAM_ATTR onDRDYFalling(void);
void print_all_ADS1299_registers_from_setup(void);
uint32_t get_baud_rate_from_config(uint8_t config_val);
















// --- Register Setup ---
typedef struct Deez { int add; int reg_val; } regVal_pair;
const int size_reg_ls = 24;
static const regVal_pair ADS1299_REGISTER_LS[size_reg_ls] = {
  {0x01, 0b10110110}, {0x02, 0b11010000}, {0x03, 0b11101100}, {0x04, 0}, {-2, -2},
  {0x05, 0b01100000}, {0x06, 0b01100000}, {0x07, 0b01100000}, {0x08, 0b01100000},
  {0x09, 0b01100000}, {0x0A, 0b01100000}, {0x0B, 0b01100000}, {0x0C, 0b01100000},
  {0x0D, 0b11111111}, {0x0E, 0b00000000}, {0x0F, 0}, {0x10, 0}, {0x11, 0}, {-2, -2},
  {0x15, 0b00000000}, {0x16, 0}, {0x17, 0}
};
















// --- Handshake from Computer ---
int handshake_packet_size = 12;
const uint8_t MSG_TYPE_TIMESTAMP = 0x02;
const uint8_t HANDSHAKE_START_MARKER_1 = 0xAA;
const uint8_t HANDSHAKE_START_MARKER_2 = 0xBB;
const uint8_t HANDSHAKE_END_MARKER_1 = 0xCC;
const uint8_t HANDSHAKE_END_MARKER_2 = 0xDD;
const uint8_t RING_BUFFER_SIZE = 24;
uint8_t ring_buffer[RING_BUFFER_SIZE];
uint8_t ring_head = 0, ring_tail = 0, ring_counter = 0;
















bool waitForTimestamp() {
  while (Serial.available() > 0 && ring_counter < RING_BUFFER_SIZE) {
      ring_buffer[ring_head] = Serial.read(); ring_head = (ring_head + 1) % RING_BUFFER_SIZE; ring_counter++;
  }
  if (ring_counter < handshake_packet_size) return false;
  for (uint8_t i = 0; i < handshake_packet_size + 3; i++) {
      uint8_t ring_index = (ring_tail + i) % RING_BUFFER_SIZE;
      if (ring_buffer[ring_index] == HANDSHAKE_START_MARKER_1 && ring_buffer[(ring_index + 1) % RING_BUFFER_SIZE] == HANDSHAKE_START_MARKER_2 && ring_buffer[(ring_index + 2) % RING_BUFFER_SIZE] == MSG_TYPE_TIMESTAMP) {
          uint32_t received_timestamp = (uint32_t)ring_buffer[(ring_index + 3) % RING_BUFFER_SIZE] << 24 | (uint32_t)ring_buffer[(ring_index + 4) % RING_BUFFER_SIZE] << 16 | (uint32_t)ring_buffer[(ring_index + 5) % RING_BUFFER_SIZE] << 8 | (uint32_t)ring_buffer[(ring_index + 6) % RING_BUFFER_SIZE];
          uint8_t reg_addr = ring_buffer[(ring_index + 7) % RING_BUFFER_SIZE];
          uint8_t reg_val = ring_buffer[(ring_index + 8) % RING_BUFFER_SIZE];
          if (reg_addr == 0x01) {
              uint32_t new_baud_rate = get_baud_rate_from_config(reg_val);
              if (new_baud_rate > 0) {
                  while (Serial.available() > 0) { Serial.read(); }
                  Serial.flush(); delay(100); Serial.begin(new_baud_rate); delay(100);
              }
          }
          _unix_timestamp_reference = received_timestamp; _millis_reference = millis(); _timestamp_initialized = true;
          delay(100); return true;
      }
  }
  return false;
}
















void IRAM_ATTR onDRDYFalling(void) { dataReady = true; }
















byte SPI_SendByte(byte data_byte, bool cont) {
  if (!cont) { digitalWrite(pin_CS_NUM, LOW); delayMicroseconds(1); }
  byte received = vspi->transfer(data_byte);
  if (!cont) { delayMicroseconds(1); digitalWrite(pin_CS_NUM, HIGH); }
  return received;
}
















void ADS1299_WREG(uint8_t regAdd, uint8_t *values, uint8_t numRegs) {
  if (_ADS1299_MODE != ADS1299_MODE_SDATAC) ADS1299_SDATAC();
  digitalWrite(pin_CS_NUM, LOW);
  delayMicroseconds(1); // FIX #1: Enforce CS setup time
  SPI_SendByte(0b01000000 | regAdd, true);
  SPI_SendByte(numRegs - 1, true);
  for (uint8_t i = 0; i < numRegs; i++) SPI_SendByte(values[i], true);
  delayMicroseconds(1); // FIX #1: Enforce CS hold time
  digitalWrite(pin_CS_NUM, HIGH);
  _ADS1299_PREV_CMD = _CMD_ADC_WREG;
}
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

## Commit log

2025-12-08 Create esp32_firmware.ino
    250sps working USBC FW SRB1
2025-12-08 Update and rename printme.txt to readme.md
2026-08-11 updated pin numbers for v2
2026-08-11 srb1 mode to diff mode...will use montage switch from now on to move modes
2026-08-11 push fw inside a folder to be able to flash with arduino ide
2026-08-11 sd card stuff in firmware fixed to stop from blocking
    [V2_FW.ino]
2026-08-12 revert fw to normal mode
    [V2_FW.ino]
2026-08-12 fixed sd card blocking issue
    [V2_FW.ino]
2026-08-12 unbrick fix
    - #include "esp_log.h" + esp_log_level_set("*", ESP_LOG_NONE) — prevents ESP-IDF from corrupting the binary protocol. Required.
    - DAT0 check in sd_init() — prevents USB CDC from being killed when no SD card is present. Required.
    - delay(500) — prevents data loss on boards with slower USB CDC init. Required.
    - DEBUG_ENABLED is commented out. The #ifdef blocks compile to nothing. No debug code is active.
    [V2_FW.ino]
2026-08-12 needed more delay
    The 500ms isn't enough. The problem is that opening the port resets the ESP32 (USB_UART_CHIP_RESET), and USB CDC takes longer to re-enumerate than 500ms. The proper fix is
    to wait for USB CDC to actually be ready, with a timeout so standalone SD logging still works.
    [V2_FW.ino]
2026-08-12 fw works - card insert check removed relying on delay bc blocking card logging
